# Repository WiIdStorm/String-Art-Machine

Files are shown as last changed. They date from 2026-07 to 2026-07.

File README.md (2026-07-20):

# String-Art-Machine
An automated String Art machine that performs both the automated nailing process and the string weaving process.

## Introduction

This project presents an automated String Art machine designed to handle both the automated nailing and string weaving processes. The system architecture integration and control flow are built upon the following core components:

* **Control Unit & Embedded System:** Powered by an **ESP32-WROOM-32** microcontroller managing real-time motion control, sensor data processing, and execution commands.
* **Software & Image Processing:** A **Python**-based framework is utilized to convert digital source images into optimized string-path coordinates and numerical control data.
* **Position Tracking & Feedback System:** To ensure high-precision positioning and prevent accumulative mechanical errors during operation, the system employs a robust feedback mechanism:
  * A **NEMA23 Closed-Loop Stepper Motor** with an integrated encoder to prevent step loss.
  * **Optical Limit Switch Endstops** serving as red-light sensors for precise homing, position validation, and path tracking.

## Hardware Components

The primary hardware and mechatronic components utilized in this project are listed below along with their corresponding visual documentation and technical reference links:

### 1. Controllers & Microcontrollers
* **Microcontroller:** [ESP32-WROOM-32](https://documentation.espressif.com/esp32-wroom-32_datasheet_en.pdf)(Handles real-time motion control and sensor data processing)

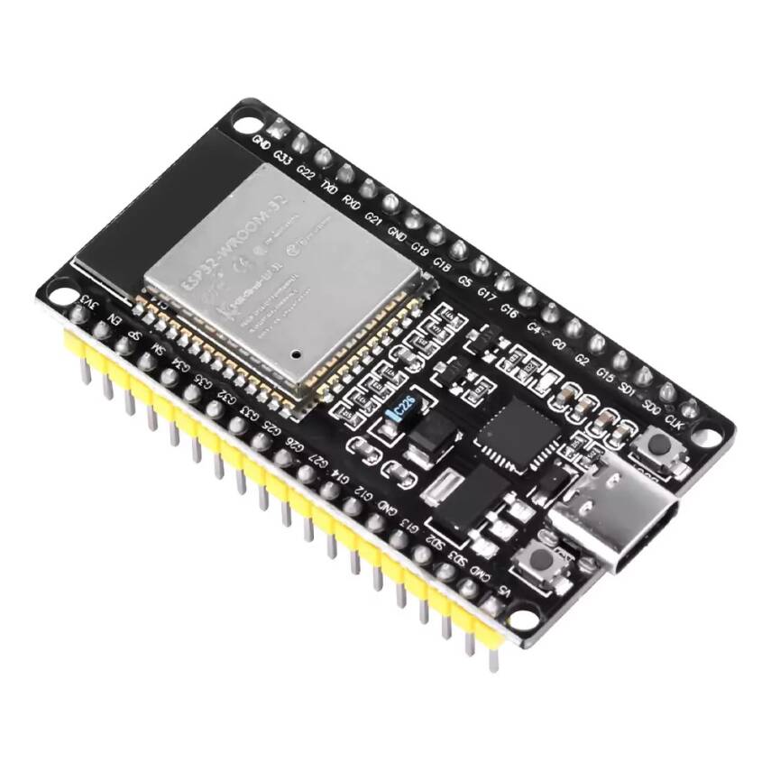
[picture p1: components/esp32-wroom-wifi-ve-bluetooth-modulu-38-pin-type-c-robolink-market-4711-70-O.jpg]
ESP32 WROOM 32


* **Signal Converters:** [MAX485 / RS485-TTL Module](https://login.pcbpower.com/Documents/0252d3ac-d61f-43a7-9b96-010299e5181c/PM14058.pdf) (Converts RS485 differential signals from encoders into TTL logic for the ESP32)

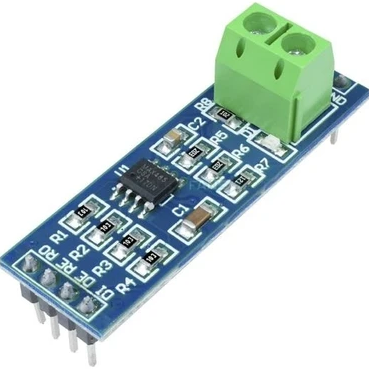
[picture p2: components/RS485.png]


### 2. Actuators, Drivers & Encoders
* **Motor:** [NEMA23 Closed Loop Stepper Motor (CS-M22323)](https://www.damencnc.com/userdata/file/6023-3_Closed_Loop_Stepper_Motor_NEMA23-2.3Nm_CS-M22323_2D_Dimensions.pdf) (2.3 Nm) with integrated encoder to prevent step loss.

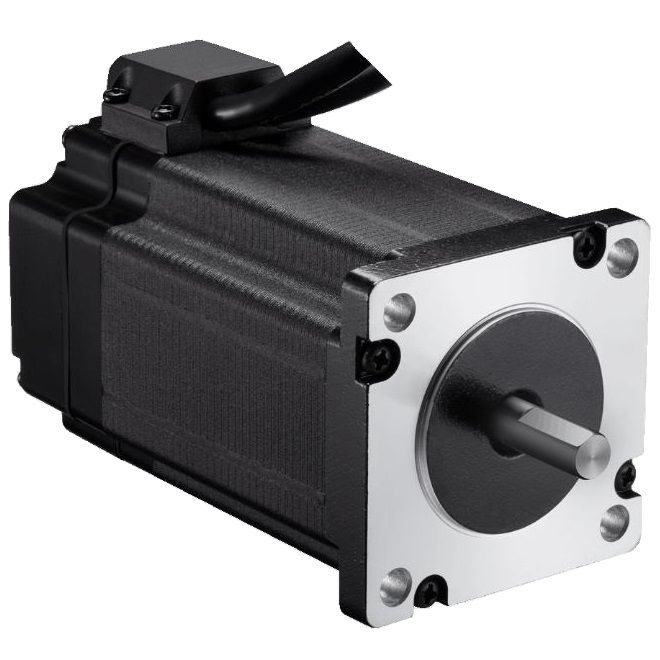
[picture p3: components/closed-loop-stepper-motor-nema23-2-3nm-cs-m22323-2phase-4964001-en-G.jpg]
NEMA23 Closed Loop Stepper Motor


* **Driver:** [CS-D508 Encoder-Integrated Stepper Motor Driver](http://leadshineusa.com/UploadFile/Down/CS-D508_m3.1.pdf) (24-48V).

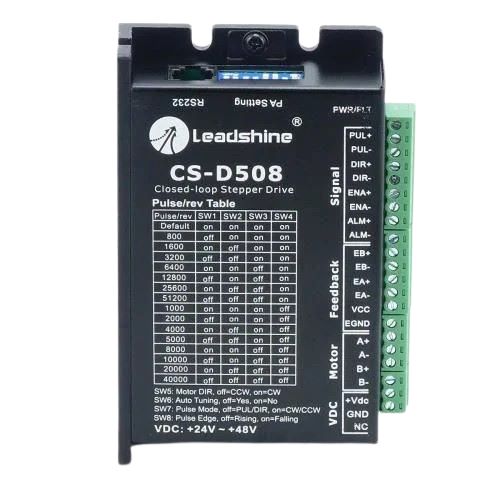
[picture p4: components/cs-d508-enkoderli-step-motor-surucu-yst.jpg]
CS-D508 Motor Driver


* **Drill Motor:** [RS-775 DC Motor](https://www.handsontec.com/dataspecs/motor_fan/775-Motor.pdf) (High-torque DC motor driving the drilling mechanism).

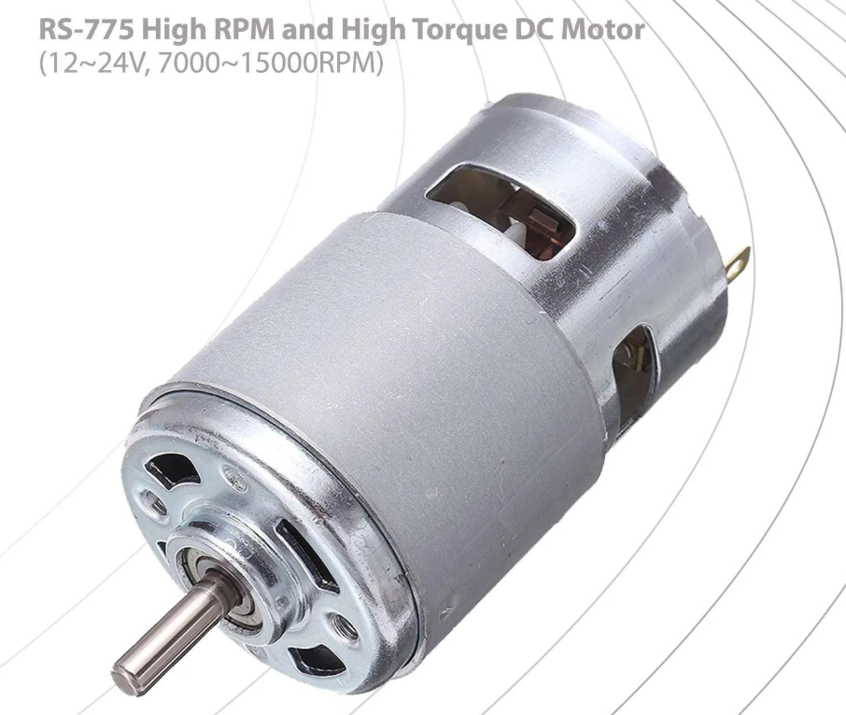
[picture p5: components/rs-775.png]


* **Servos:** [MG995 TowerPro Metal Gear Servo](https://www.electronicoscaldas.com/datasheet/MG995_Tower-Pro.pdf) (High-torque servos used for the drill depth actuation and slider mechanisms).

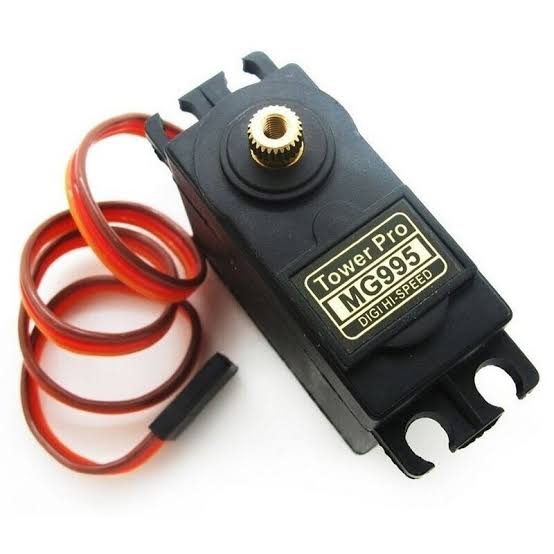
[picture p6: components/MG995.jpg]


### 3. Power Supplies (SMPS)
The system utilizes dedicated Switch Mode Power Supplies to separate power stages for stability:
* **48V Supply:** [MT-500-48 SMPS](https://mervesanteknoloji.com/statics/file/MT-500-xx-_2.pdf) (48V, 10A) - Powering the main motor drivers.

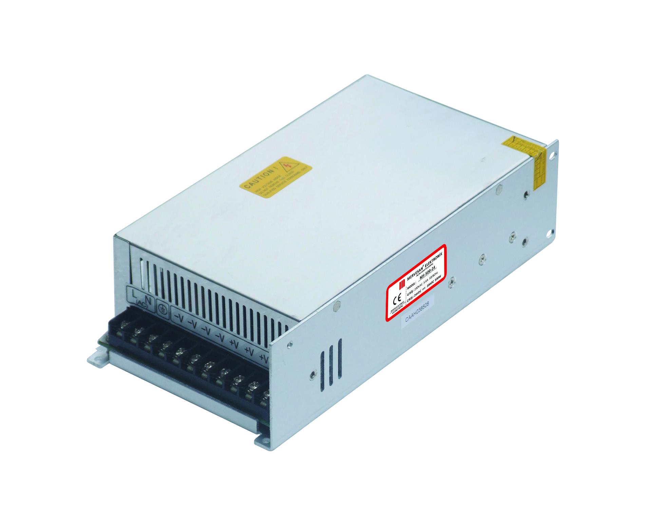
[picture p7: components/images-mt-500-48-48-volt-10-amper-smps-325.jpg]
48V 10A SMPS


* **36V Supply:** [MT-350-36 SMPS](https://mervesanteknoloji.com/statics/file/2020-6-8_user_manual_MT-350-XX_2_1.pdf) (36V, 10A).

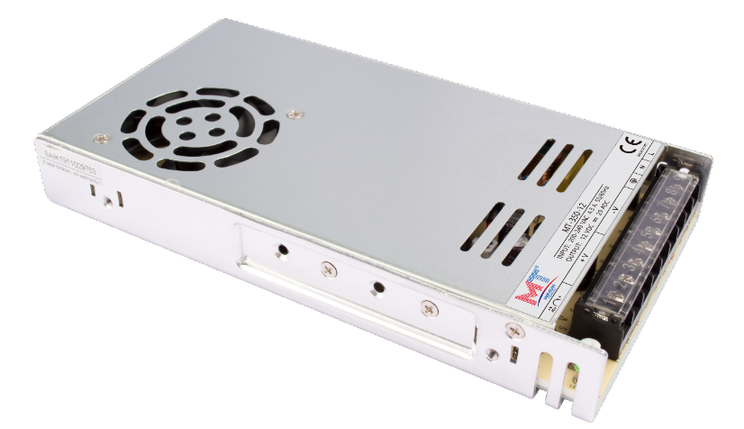
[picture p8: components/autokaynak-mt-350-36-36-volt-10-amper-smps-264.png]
36V 10A SMPS


* **24V Supply:** [Mervesan MT-250-24 SMPS](https://mervesanteknoloji.com/statics/file/MTLRS-250-24_Manua_ver-1.0.pdf) (24VDC, 10A).

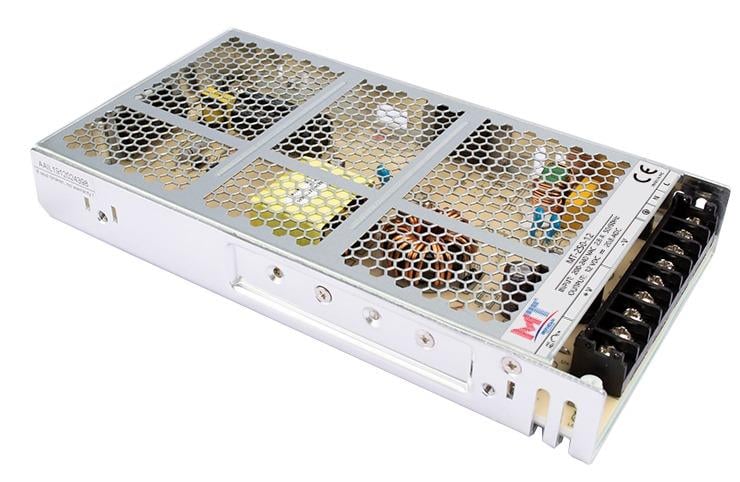
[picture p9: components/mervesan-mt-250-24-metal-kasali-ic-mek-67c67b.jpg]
24V 10A SMPS


### 4. Voltage Regulation (DC-DC Step-Down)
* **High-Power Buck Converters:** 3x [XL4016 DC-DC Step Down Regulator Modules](https://www.mikrocontroller.net/attachment/534859/XL4016_Step_Down_Buck_DC_DC_Converter.pdf) (300W, 10A).
  * *Note on Implementation:* One of these buck converters replaces a standard XL4016 module, as the high-capacity XL4016 was readily available and deployed to maintain power consistency across the logic and sensor circuits.

| XL4016 300w | XL4016 200w |
| :---: | :---: |
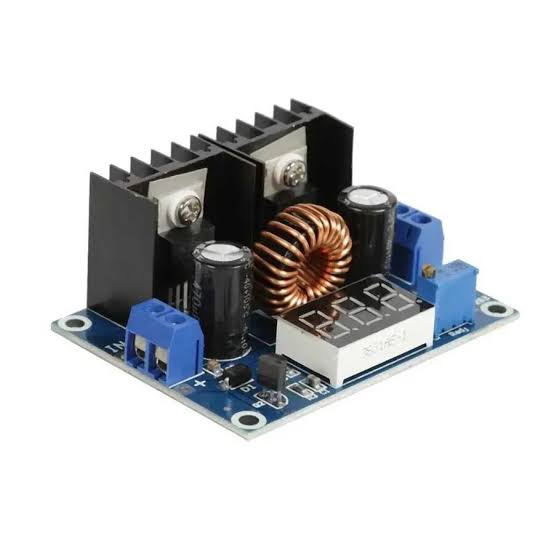
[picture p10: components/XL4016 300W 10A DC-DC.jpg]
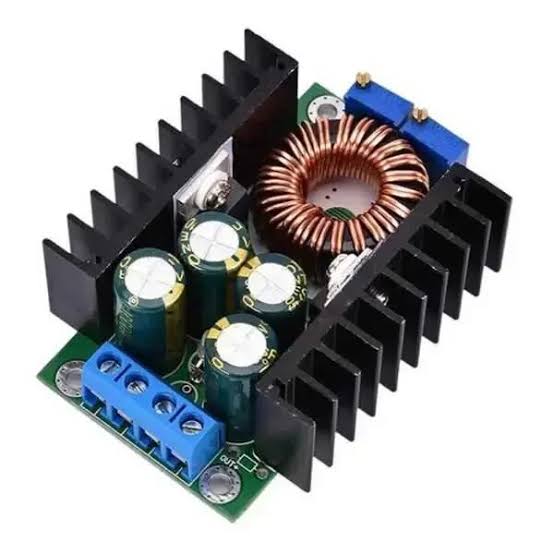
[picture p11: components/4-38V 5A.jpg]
|  |  |

### 5. Sensors & Position Tracking
* **Optical Sensors:** [Optical Limit Switch Endstops](https://www.handsontec.com/dataspecs/sensor/Optical%20end%20stop.pdf) (Dimensions: 33 x 12 x 10 mm) used for precise homing, position validation, and path tracking.

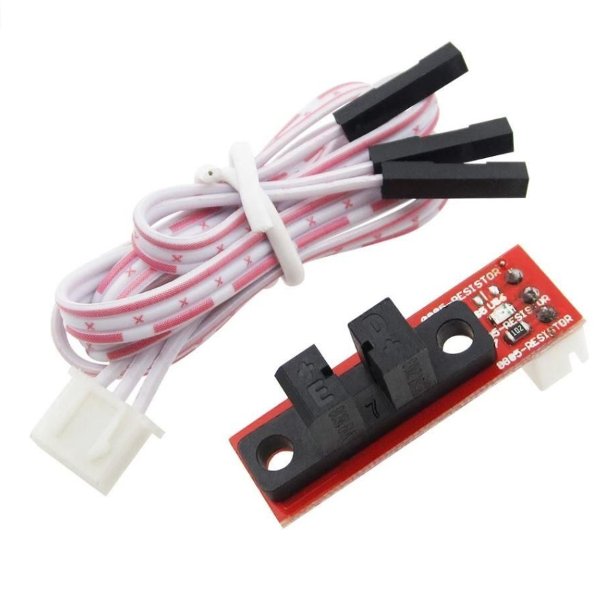
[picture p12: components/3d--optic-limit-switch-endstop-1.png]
Optical Limit Switch Endstop


## Mechanical Design & Assembly

The mechanical structure of the String Art machine is detailed in this section. The design progresses from the top-level system assembly down to the individual custom-designed components.

### 1. System Overview (Top View)
The main layout of the system, illustrating the positioning and integration of the mechanical and electronic sub-assemblies, is provided below.

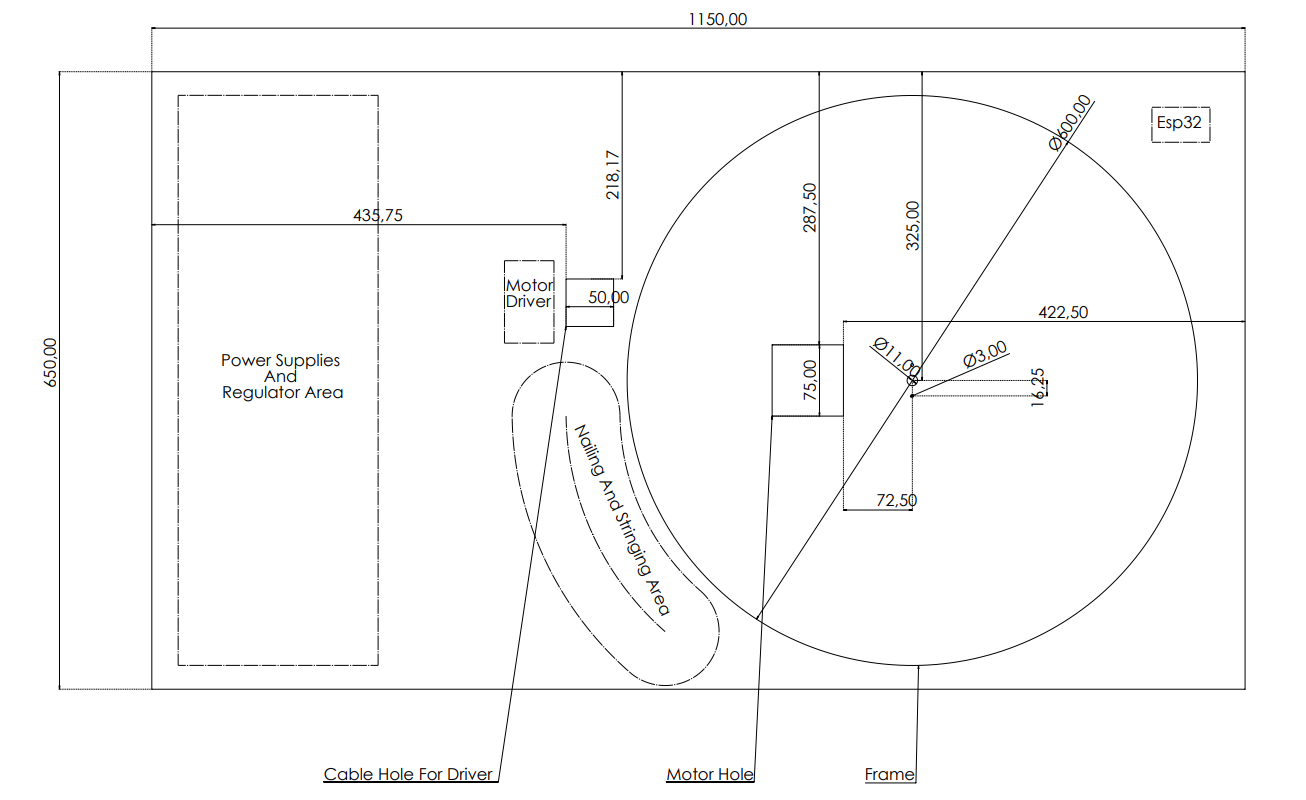
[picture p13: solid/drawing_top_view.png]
Top View Technical Drawing


* **Top View Drawing:** [`drawing_top_view.pdf`](./solid/drawing_top_view.pdf)
### 2. Custom Components
The following custom parts were designed for the physical construction of the machine. Universal `.step` files are provided for replication, alongside visual references for each component.

* **Drill Main Unit:** Core housing for the drilling mechanism.
  
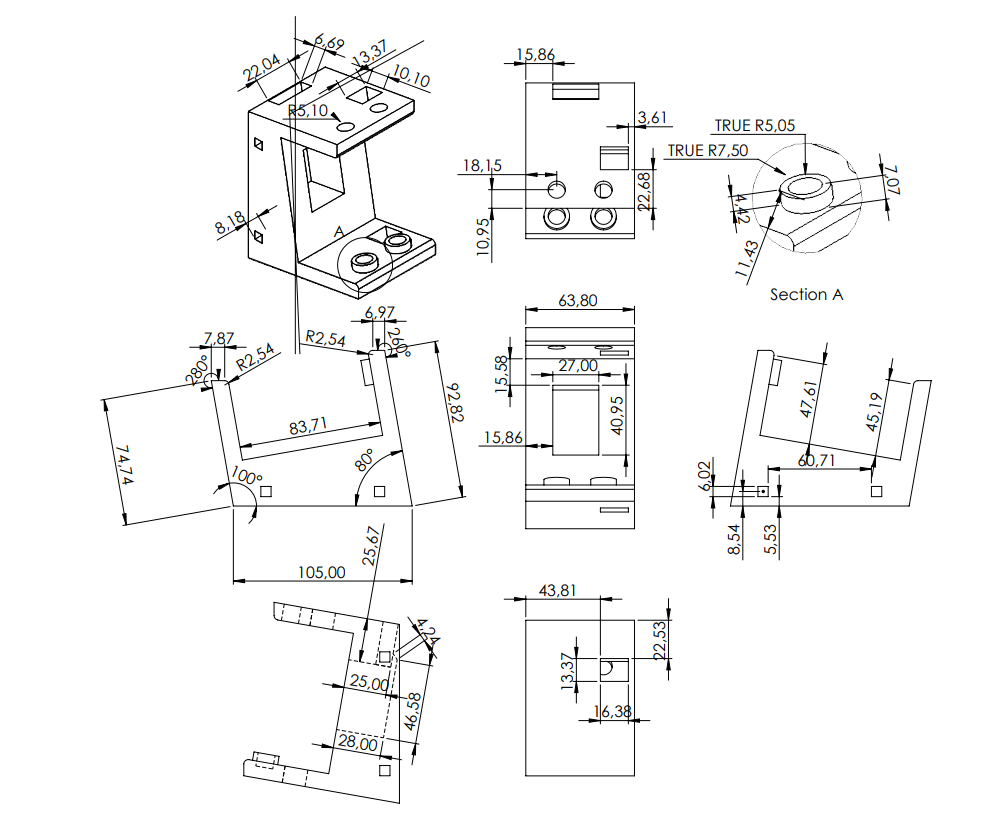
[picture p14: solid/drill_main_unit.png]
  

  * **File:** [`drill_main_unit.step`](./solid/drill_main_unit.step)
* **Drill Mounting Rod:** Structural support component for the drill unit.
  
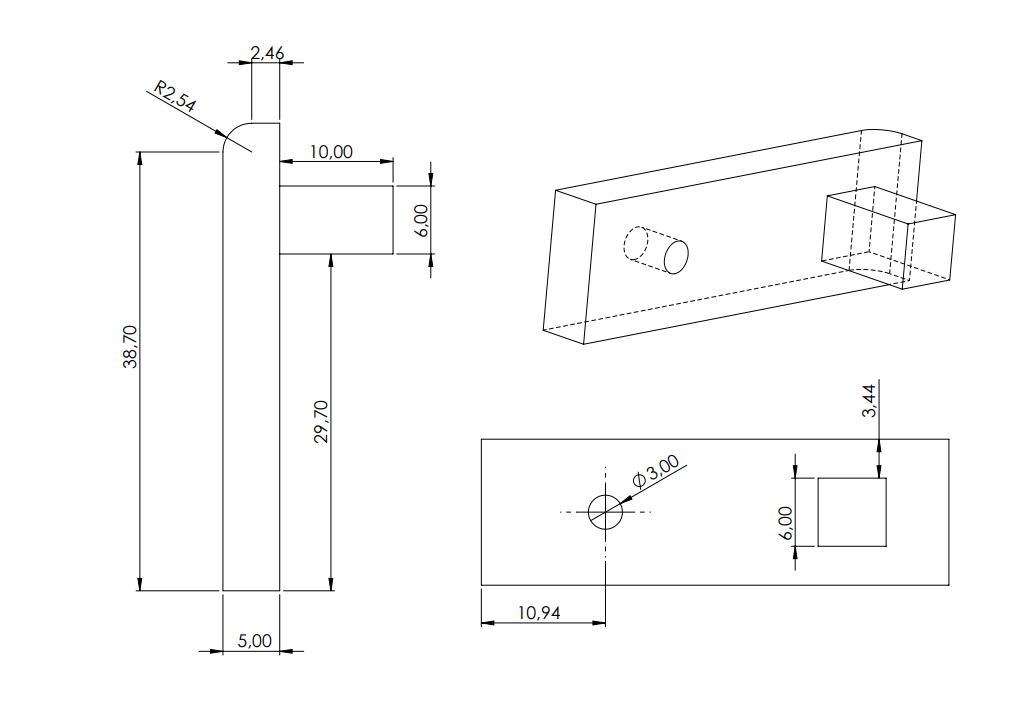
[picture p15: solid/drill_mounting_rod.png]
Drill Mounting Rod
  

  * **File:** [`drill_mounting_rod.step`](./solid/drill_mounting_rod.step)
* **Drill Servo Gear:** Transmission gear for the servo-actuated mechanism.

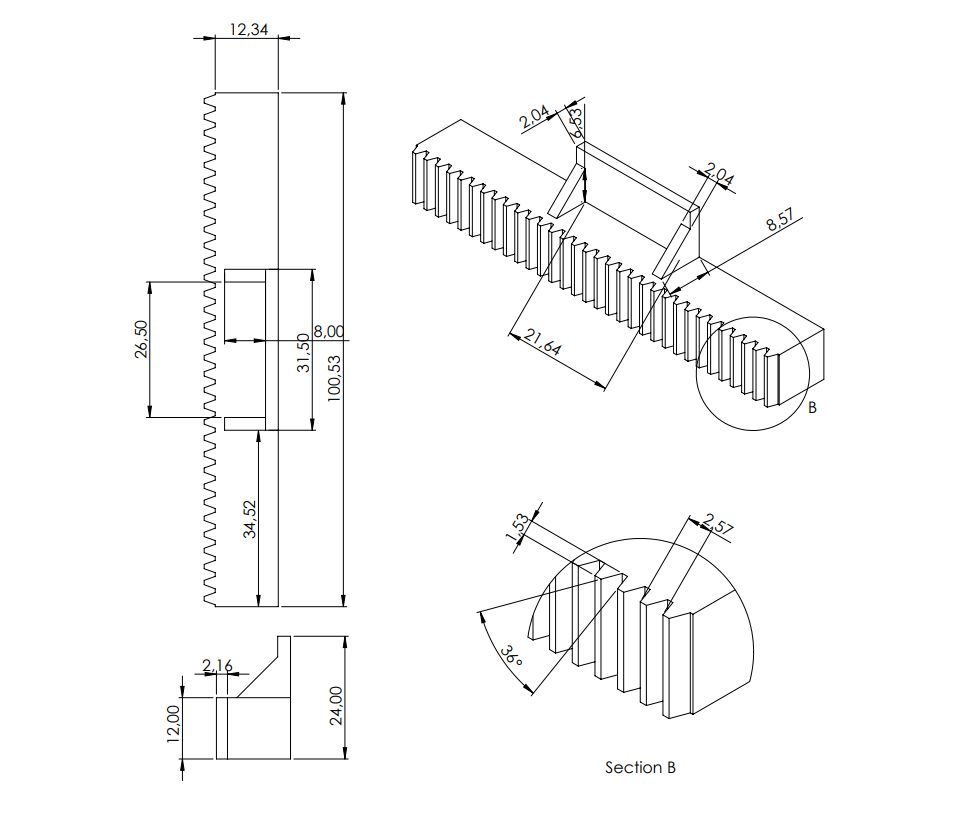
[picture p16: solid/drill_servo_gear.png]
Drill Servo Gear
  

  * **File:** [`drill_servo_gear.step`](./solid/drill_servo_gear.step)
* **Motor Mount:** Bracket designed to secure the NEMA23 closed-loop stepper motors.
  
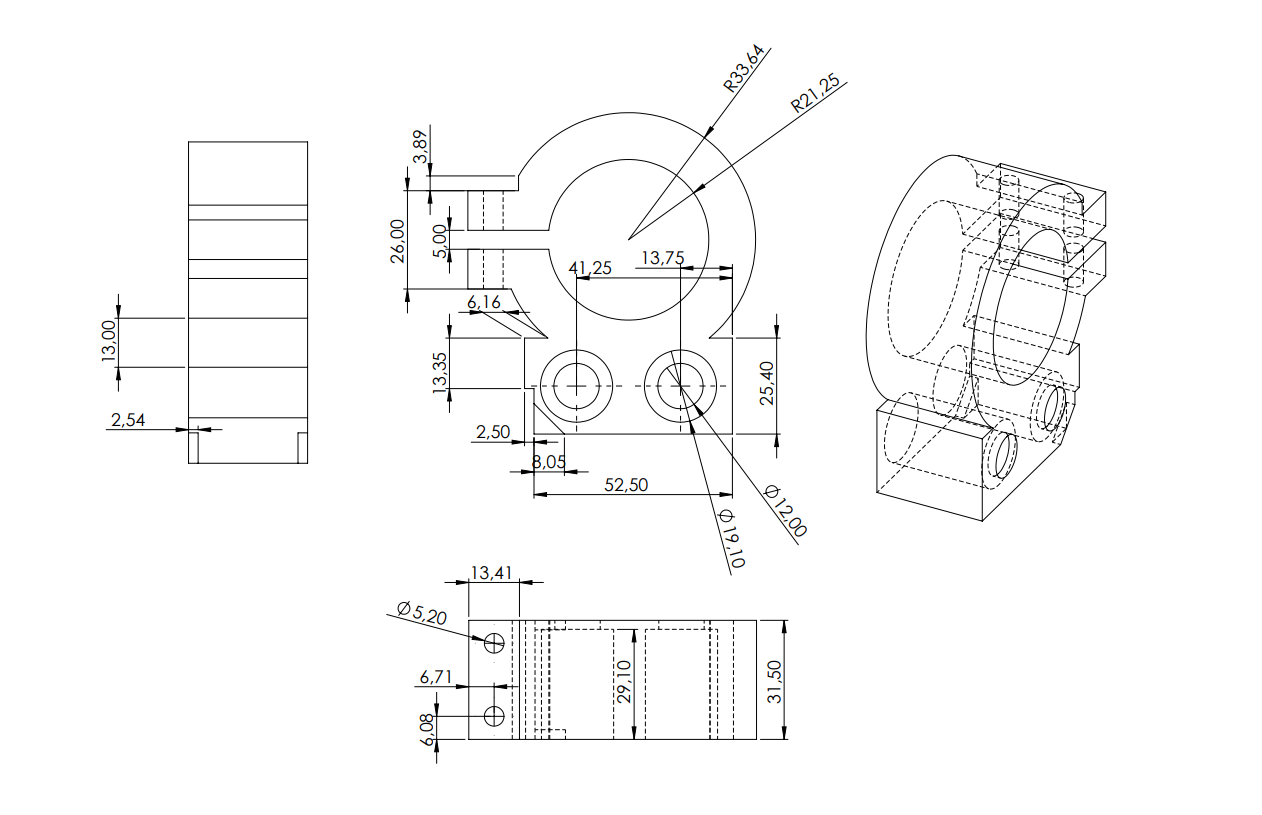
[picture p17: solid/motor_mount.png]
Motor Mount
  

  * **File:** [`motor_mount.step`](./solid/motor_mount.step)
* **Slider End:** End effector and guide component for the linear motion axis.
  
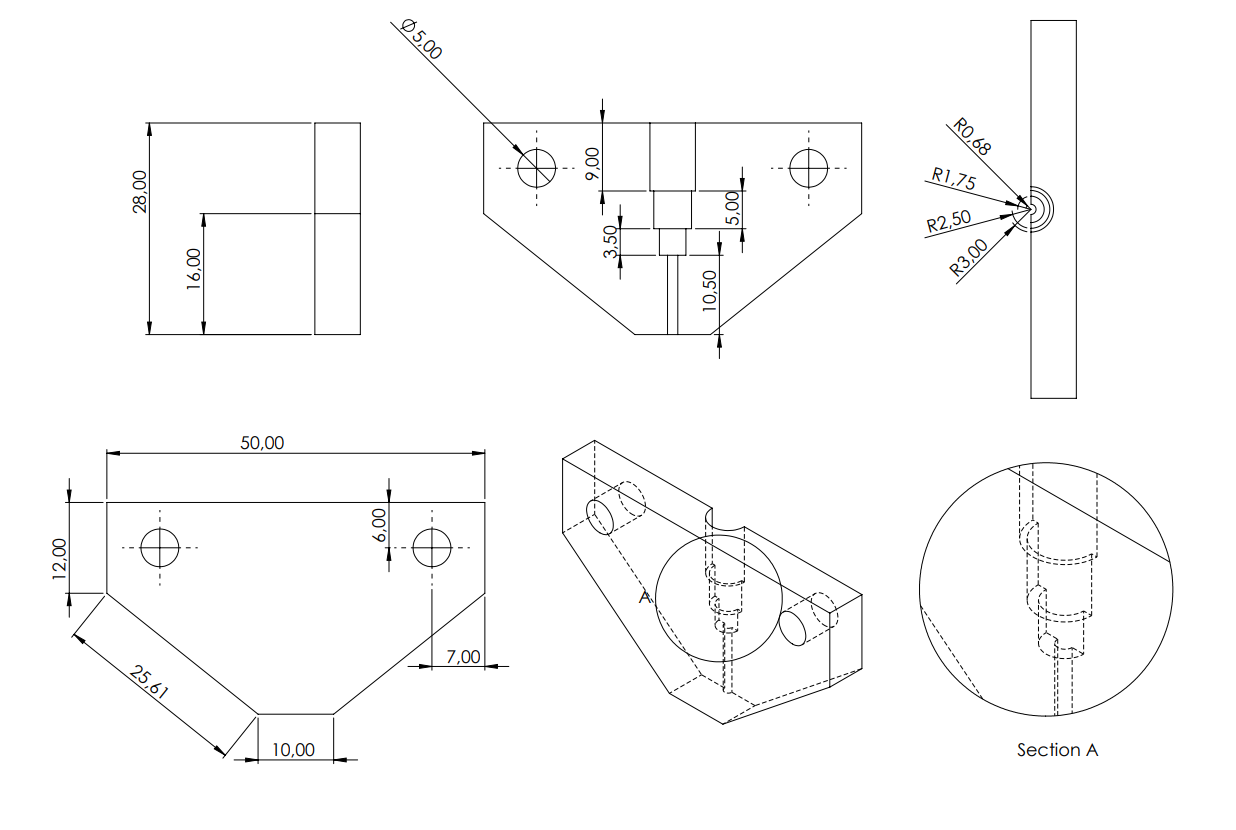
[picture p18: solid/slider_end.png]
Slider End
  

  * **File:** [`slider_end.step`](./solid/slider_end.step)
* **Chassis:** The primary structural frame supporting the entire operation.
 
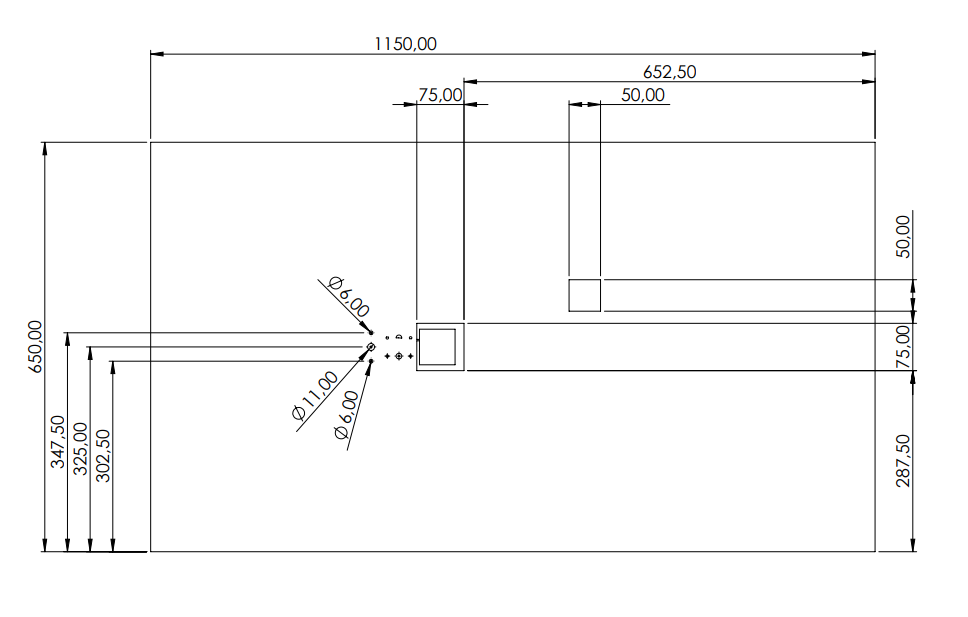
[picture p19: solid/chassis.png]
Chassis
  

  * **File:** [`chassis.step`](./solid/chassis.step)
* **Table / Bed:** The main work surface where the string art generation takes place.
  
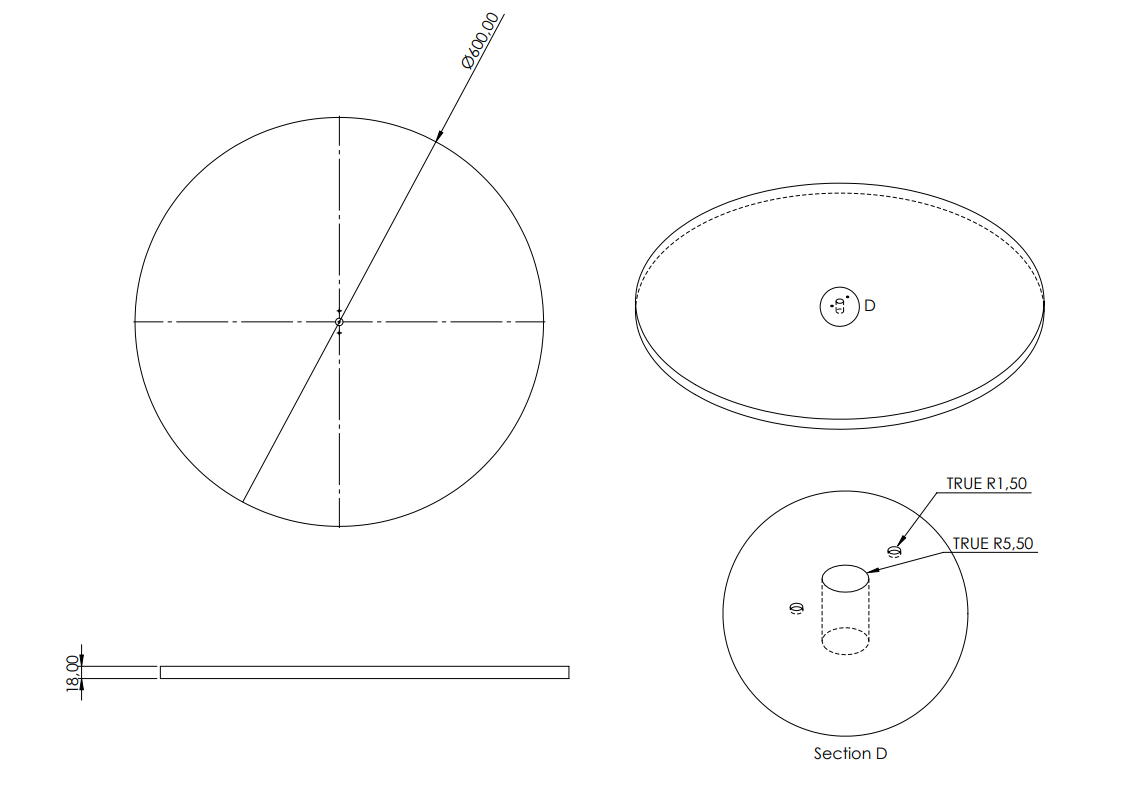
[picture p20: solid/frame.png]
Frame
  

   * **File:** [`table_bed.step`](./solid/frame.step)

## System Wiring & Connections

To ensure system stability, prevent step loss, and protect the low-voltage microcontroller components, the electrical architecture is divided into three isolated stages. 

*(Note: Ensure all sub-systems share a physical **Common GND** network to prevent signal noise).*

### 1. Power Distribution Layout
This section details the AC-to-DC power routing, voltage regulation stages, and the common ground network used to power the system.

* **AC Mains Input:** 220V AC grid ($L, N, \text{PE}$) supplies power to the primary SMPS units.
* **Main SMPS Units (Power Supply):** 
  * **MT-500-48 SMPS (48V, 10A):** Dedicated to powering the main NEMA23 closed-loop stepper motor driver (CS-D508).
  * **MT-350-36 SMPS (36V, 10A):** Supplies power for the auxiliary motor drivers.
  * **Mervesan MT-250-24 SMPS (24V, 10A):** Provides base voltage for DC motor drivers and DC-DC step-down modules.
* **DC-DC Step-Down Stages (Voltage Regulation):**
  * **XL4016 Buck Converter 1:** Steps down voltage to **5V** to supply logic power for sensors, encoders, servos, and level shifters.
  * **XL4016 Buck Converter 2:** Steps down voltage to **3.3V** to power the ESP32 microcontroller.

### 2. Logic Level Shifting & MCU Interface
This section details the control signal pathways and pin mappings between the low-voltage ESP32 and the 5V peripheral interfaces.

The ESP32 operates at a **3.3V logic level**. Level shifters are dedicated specifically to stepping down **5V signal outputs** (such as encoder receiver outputs, sensor signals, and driver feedback) down to **3.3V** to protect the ESP32 GPIO pins, while control output signals are driven directly from the microcontroller.

| Component | Signal Type | ESP32 Pin (3.3V) | Level Shifter Direction | Peripheral Pin (5V) |
| :--- | :--- | :---: | :---: | :--- |
| **Stepper Driver (CS-D508)** | Pulse | `P18` | Direct (3.3V) | `PUL+` (Blue) |
| | Direction | `P19` | Direct (3.3V) | `DIR+` (Brown) |
| | Enable | `P17` | Direct (3.3V) | `ENA+` (Green) |
| | Alarm | `P16` | 5V $\rightarrow$ 3.3V | `ALM+` (Orange) |
| **DC Motor Driver (BTS7960)**| Forward PWM | `P26` | Direct (3.3V) | `RPWM` |
| | Reverse PWM | `P27` | Direct (3.3V) | `LPWM` |
| | Right Enable | `P25` | Direct (3.3V) | `R_EN` |
| | Left Enable | `P25` | Direct (3.3V) | `L_EN` |
| **Servos (MG995)** | Drill PWM | `P21` | Direct (3.3V) | Signal (Drill Servo) |
| | Slider PWM | `P14` | Direct (3.3V) | Signal (Slider Servo) |
| **Encoders (RS485-TTL)** | Encoder 1 (RO) | `P22` | 5V $\rightarrow$ 3.3V | `RO` (Green/Red) |
| | Encoder 2 (RO) | `P23` | 5V $\rightarrow$ 3.3V | `RO` (Yellow/Blue) |
| **Sensors** | Optical Sensor | `P32` | 5V $\rightarrow$ 3.3V | Signal Output |

### 3. Actuators & Closed-Loop Feedback Connections
This section outlines the high-current drive outputs, motor phase connections, and hardware-level feedback routing.

* **Main Motion Control:**
  * The **CS-D508 Stepper Driver** receives power from the 48V SMPS and outputs high-current drive signals to the **NEMA23 Closed-Loop Stepper Motor (CS-M22323)** phases.
  * **Feedback Loop:** The integrated encoder on the rear of the NEMA23 motor routes directly back to the dedicated feedback port on the CS-D508 driver. This ensures hardware-level correction to prevent step loss without adding processing overhead to the ESP32.
* **Auxiliary Actuation (Nailing & Stringing Mechanisms):**
  * The **BTS7960 DC Motor Driver** controls the **RS-775 DC Motor** for high-torque operations (such as the drilling/nailing spindle).
  * The **MG995 Servos** draw power from the 5V regulated line and receive direct PWM signals from the ESP32 to actuate the slider and depth mechanisms.

## System Integration & Real-World Assembly

This section documents the physical construction of the String Art machine, showcasing the integration of mechanical parts, electronics, and the execution of the main automated processes.

### 1. Electronics & Control Assembly
* **ESP32 & Breakout Integration:** Real-world wiring and terminal block assignments on the main ESP32 development board.

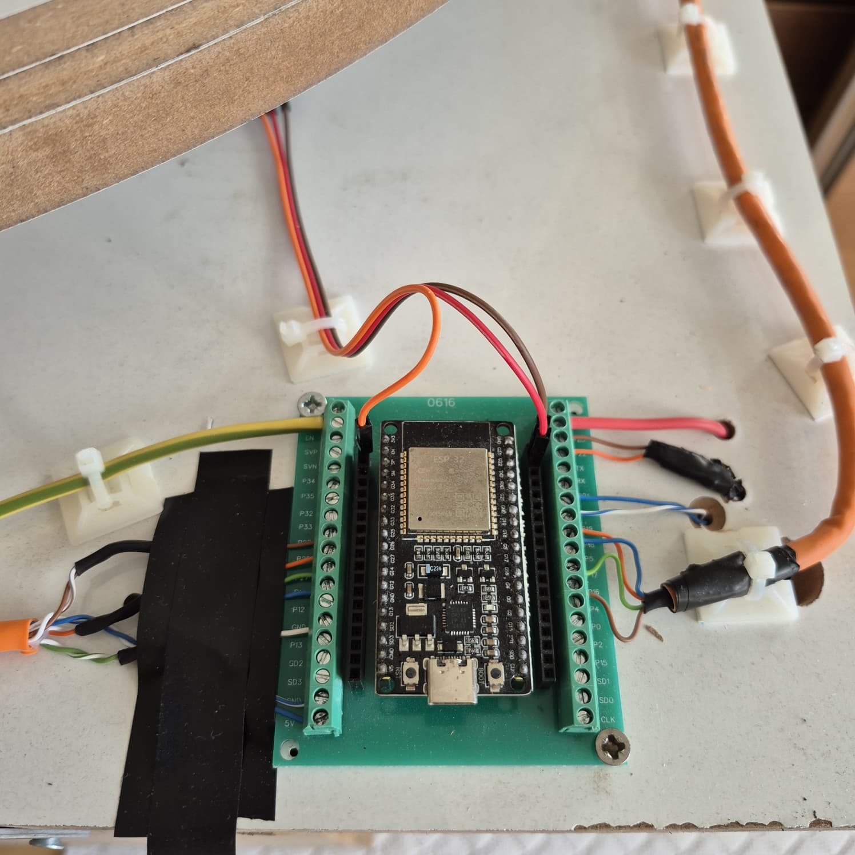
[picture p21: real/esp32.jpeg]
ESP32 Controller Unit
  

* **Stepper Driver & Signal Cabling:** Industrial CS-D508 stepper motor driver wired to the motor phase lines and control bus.

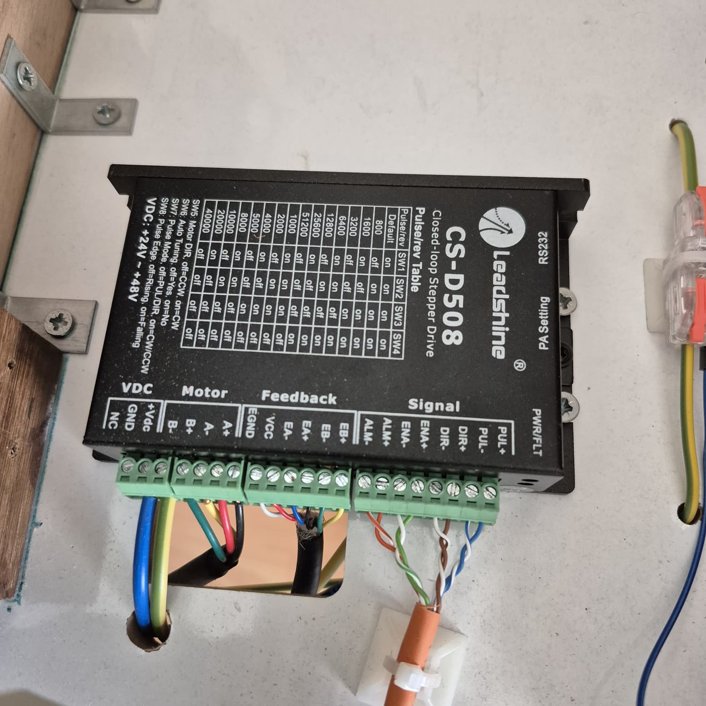
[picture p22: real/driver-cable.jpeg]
CS-D508 Stepper Driver Wiring
  

* **Logic Level Shifting & RS485 Interface:** Breadboard-based signal conditioning circuits for level shifting and differential encoder communication.

| Encoder Signal Converter | Signal Shifter (Far Side) |
| :---: | :---: |
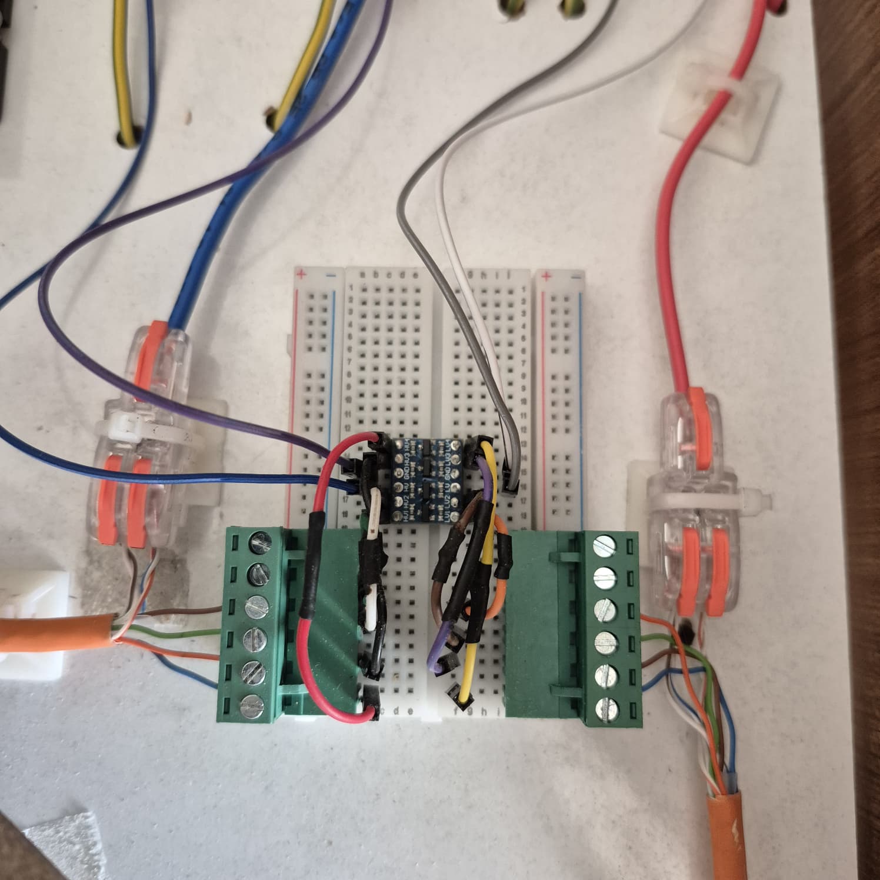
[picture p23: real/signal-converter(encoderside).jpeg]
Encoder Signal Converter
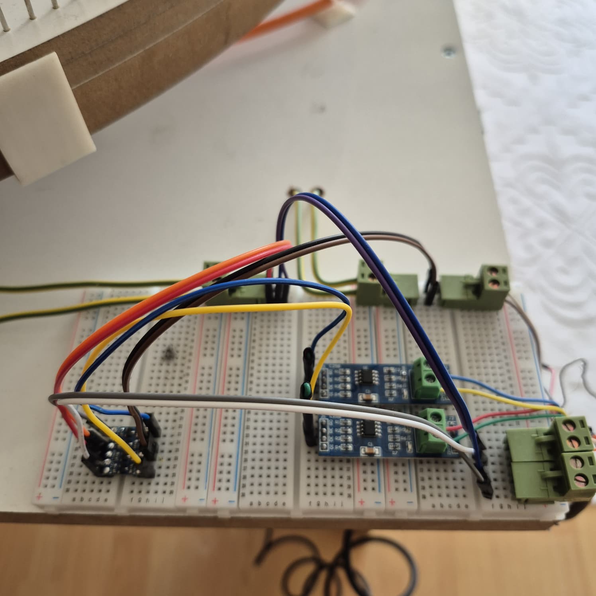
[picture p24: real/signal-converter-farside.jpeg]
Signal Converter Overview
|  |  |

---

### 2. Mechanical Integration & Feedback System
* **Rotary Encoder Assembly:** Direct shaft-coupled rotary encoder for mechanical feedback and position tracking.

| Bed Encoder Mount | Dual Motor & Encoder Integration |
| :---: | :---: |
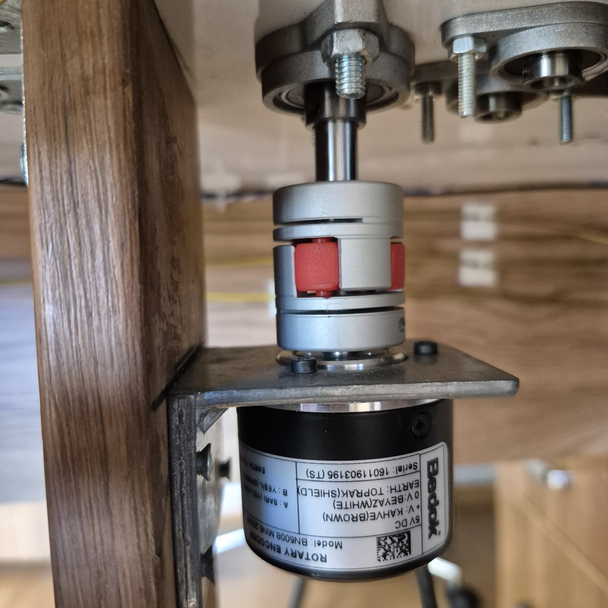
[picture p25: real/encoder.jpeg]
Rotary Encoder Assembly
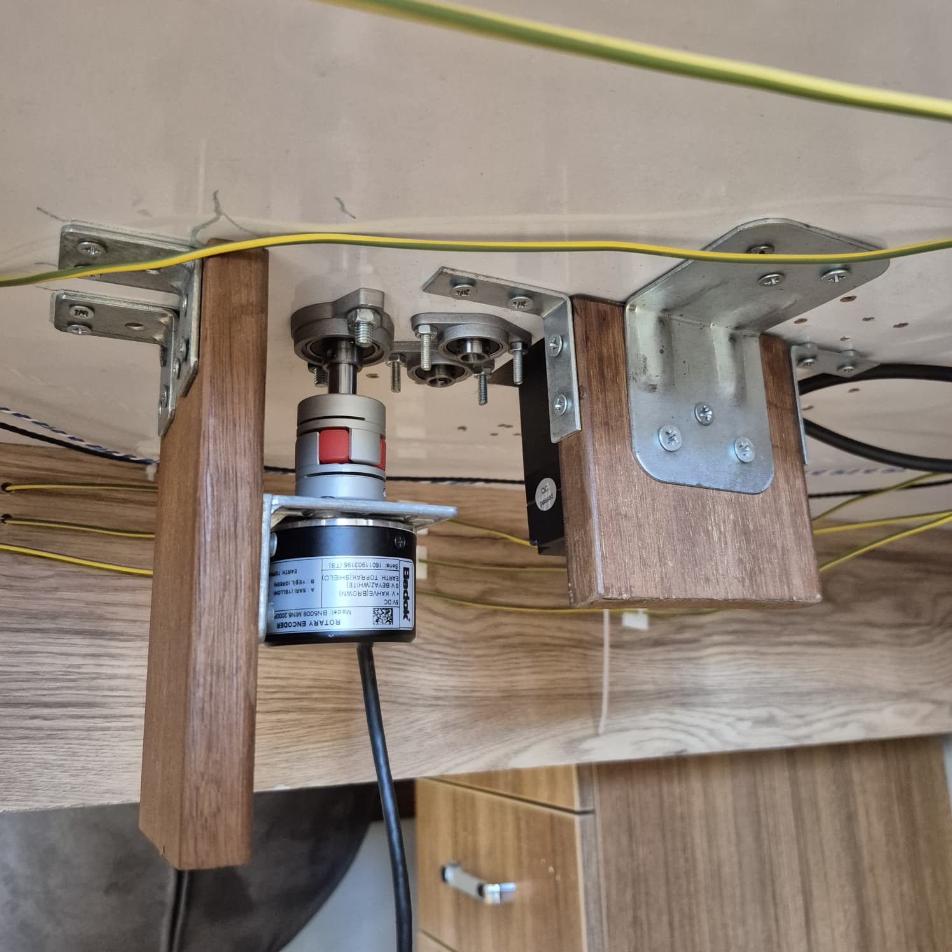
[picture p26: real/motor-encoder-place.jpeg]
Motor and Encoder Setup
|  |  |

* **Optical Homing Sensor:** Precision limit switch mounted near the rotating bed for absolute zero position validation.

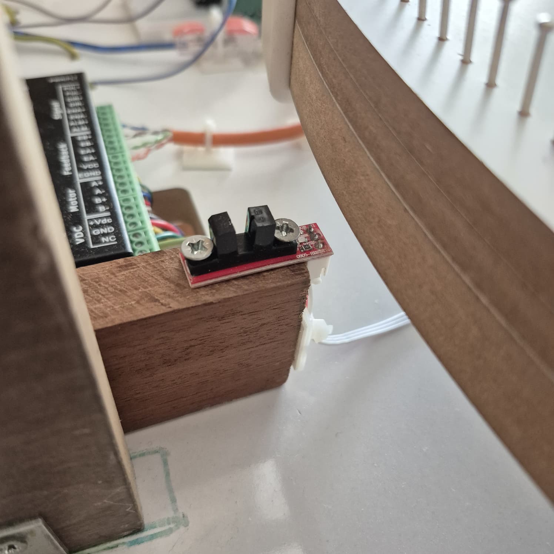
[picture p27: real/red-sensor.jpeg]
Optical Limit Switch
  

* **Power Supply & Chassis Mobility:** Power stage distribution layout and structural support caster installation.

| Power & Main Motor Setup | Chassis Caster Support |
| :---: | :---: |
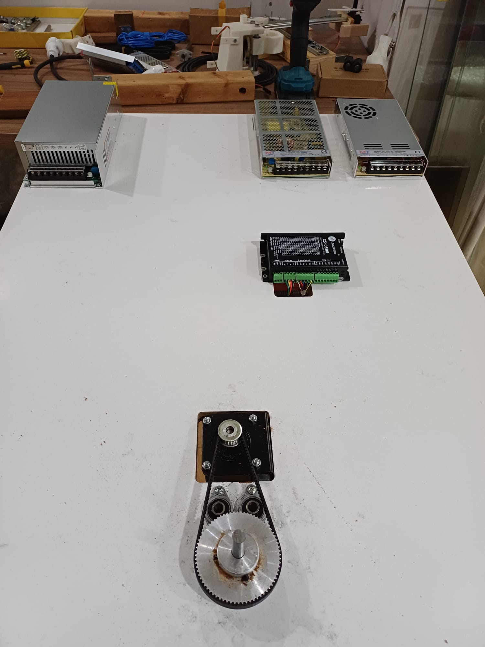
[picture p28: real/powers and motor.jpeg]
Power Supply Layout
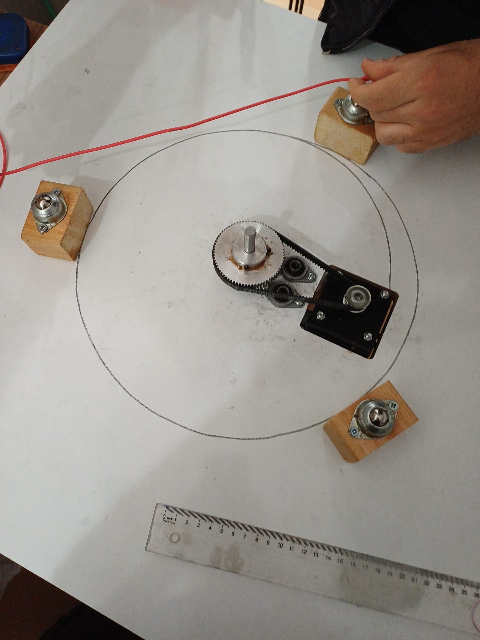
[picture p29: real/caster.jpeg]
Caster Wheel Support
|  |  |

---

### 3. Operational Stages
* **Automated Nailing Process:** The end-effector mechanism drilling guidelines and precisely inserting pins/nails into the circular bed.

| Nailing Assembly 1 | Nailing Assembly 2 | Nailing Circuit |
| :---: | :---: | :---: |
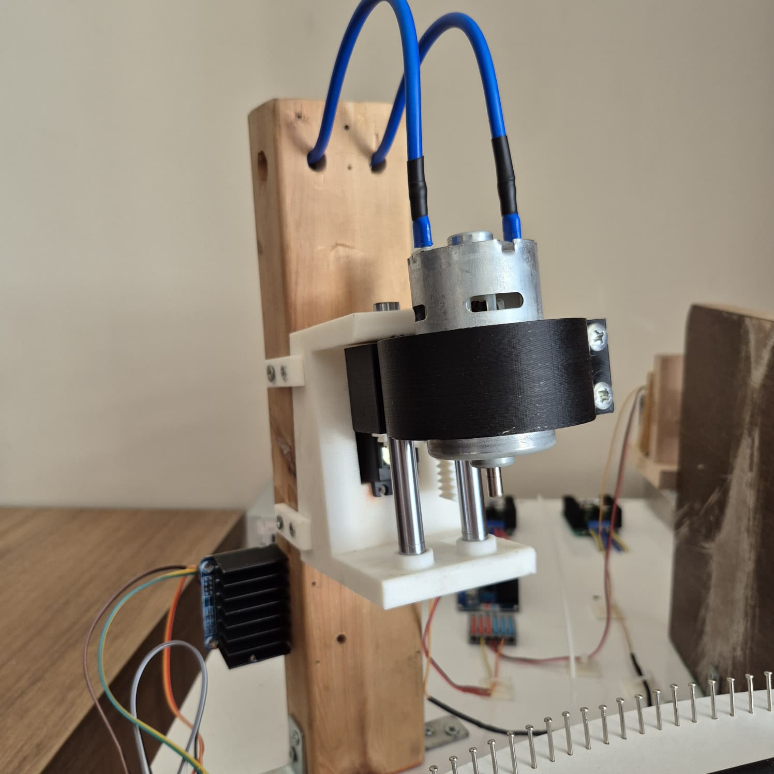
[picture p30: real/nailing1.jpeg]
Automated Nailing Process 1
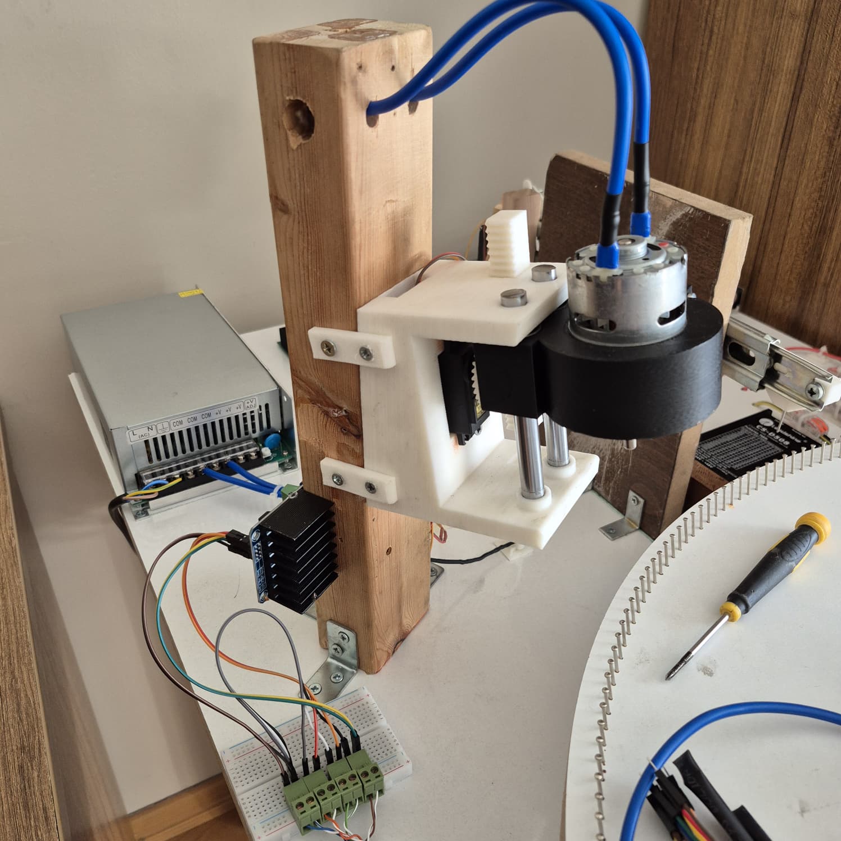
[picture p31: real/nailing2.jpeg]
Automated Nailing Process 2
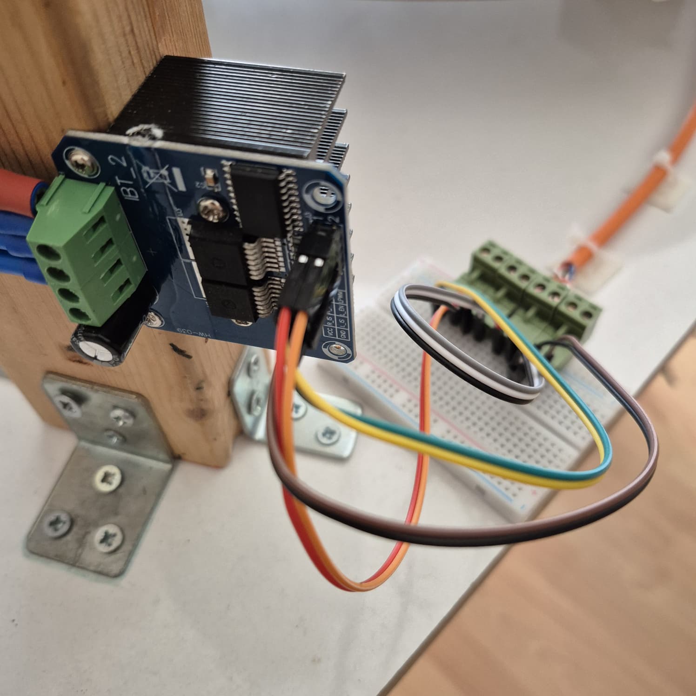
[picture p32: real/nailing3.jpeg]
Automated Nailing Process 3
|  |  |  |

* **String Weaving Process:** The automated routing of the string across the predefined coordinate paths.

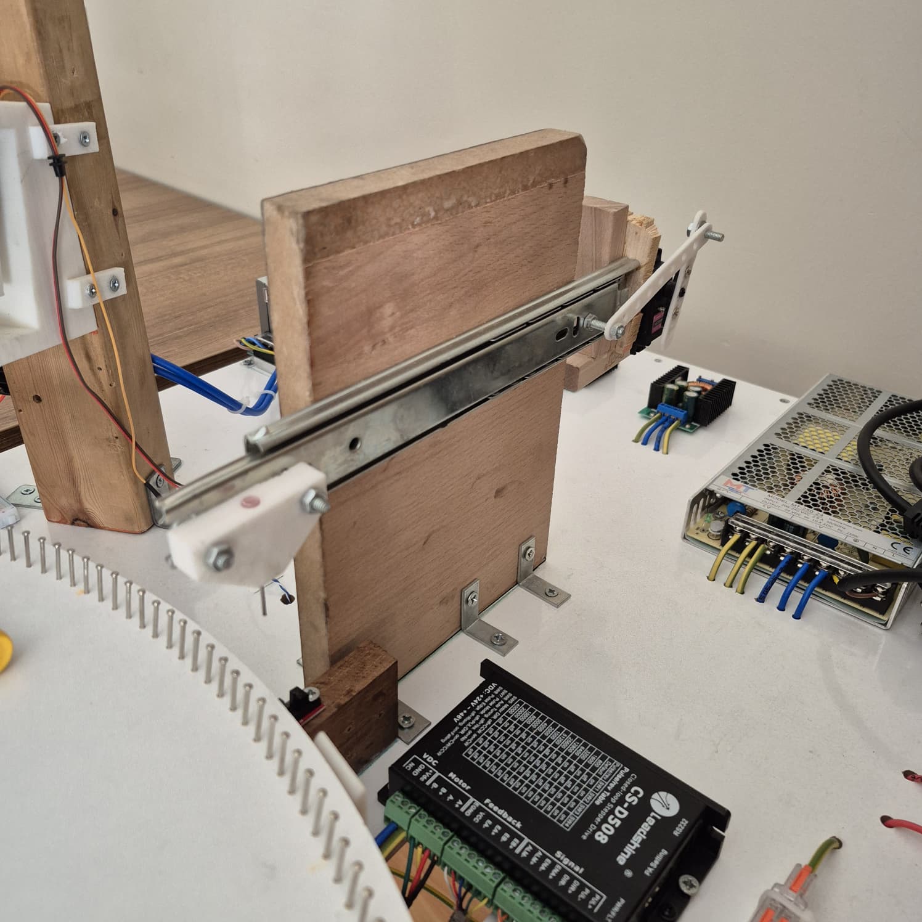
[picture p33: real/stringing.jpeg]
String Weaving Process
  

## Software Architecture & Algorithm Breakdown

This section documents the software framework and the core image-to-string processing pipeline. The complete source code files are hosted directly within the repository files.

### 1. Image Processing & String Generation Pipeline
The **Python**-based framework processes digital source images, applies localized optimization algorithms, and generates numerical control paths for the ESP32 microcontroller.

**Key Software Modules & Operations to Document:**
* **Image Pre-processing Module:** Grayscale conversion, contrast adjustment, and cropping filters.
* **Algorithm Core:** Calculations mapping string density, line intersections, and nail-to-nail path sequences.
* **Data Exporter:** Generation of numerical control data arrays and transmission protocols sent to the ESP32.

### 2. Algorithmic Transformation (Sample Input vs. Output)
Below is a visual representation of how the Python pipeline transforms a standard raster image into a vector-mapped string-art pattern:

| Source Input Image (Girdi) | Algorithmic String Output (Çıktı) |
| :---: | :---: |
| Original Input Image | Generated String Art Result |

---

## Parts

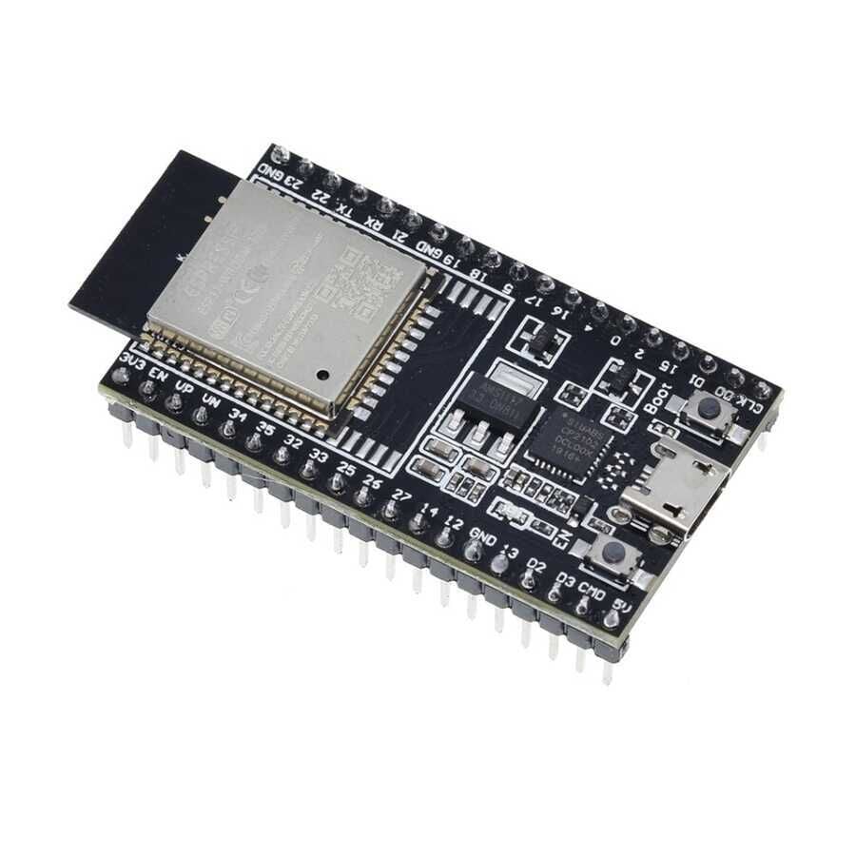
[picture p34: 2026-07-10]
components/esp32-wroom-32d-wifi-ve-bluetooth-gelistirme-karti-1.jpg

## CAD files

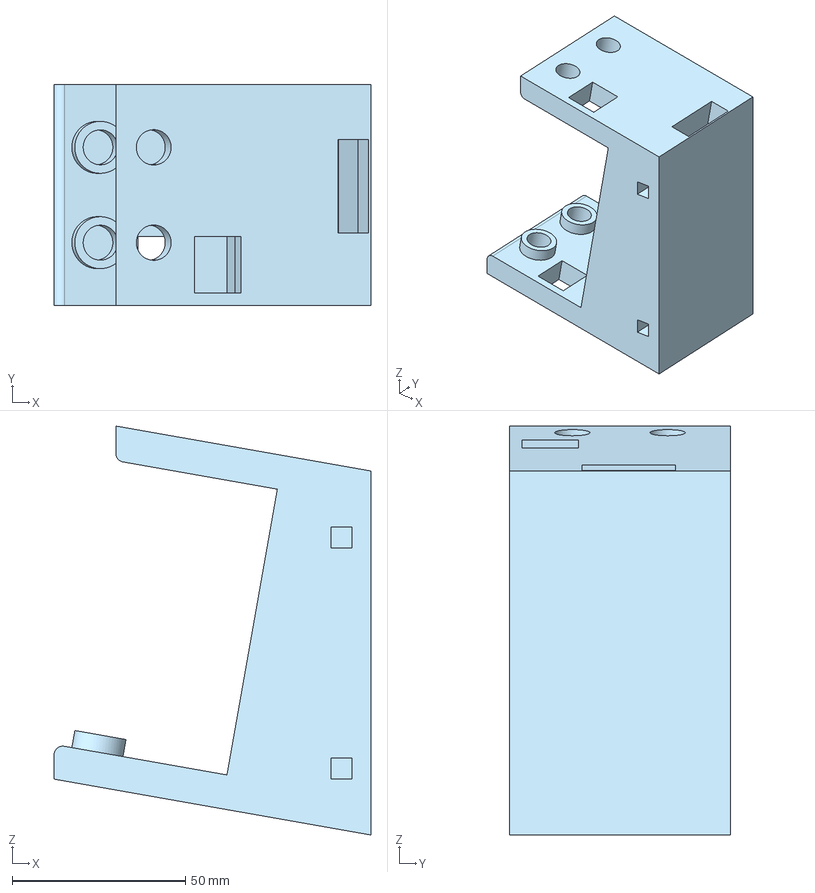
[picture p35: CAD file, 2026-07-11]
solid/drill_main_unit.step
91.4 x 63.8 x 118.0 mm

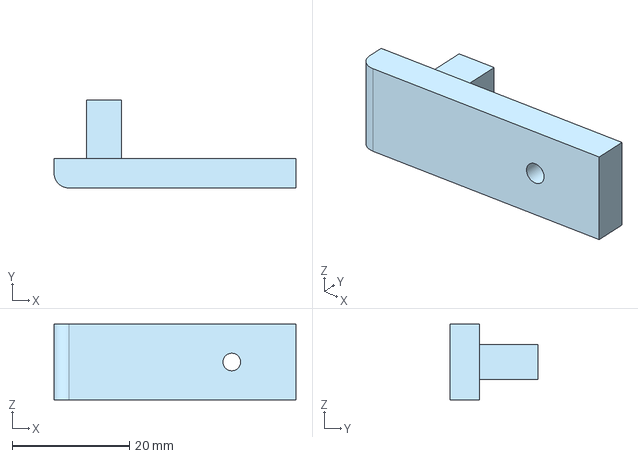
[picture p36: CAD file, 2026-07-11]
solid/drill_mounting_rod.step
41.2 x 15.0 x 12.9 mm

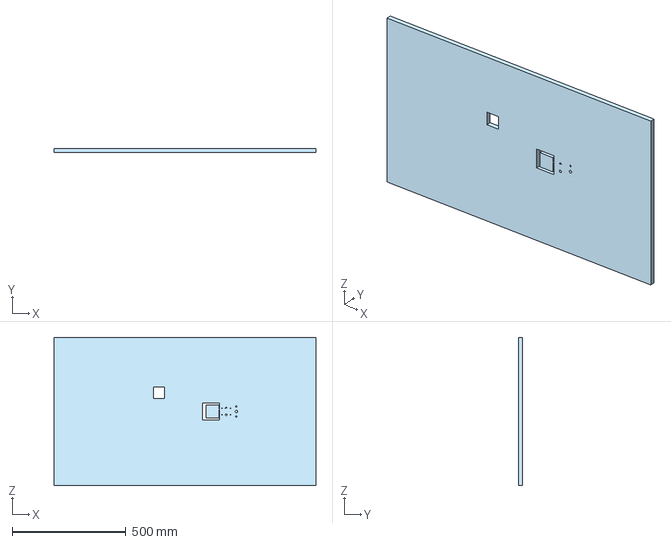
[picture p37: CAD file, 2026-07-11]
solid/chassis.step
1150.0 x 18.0 x 650.0 mm

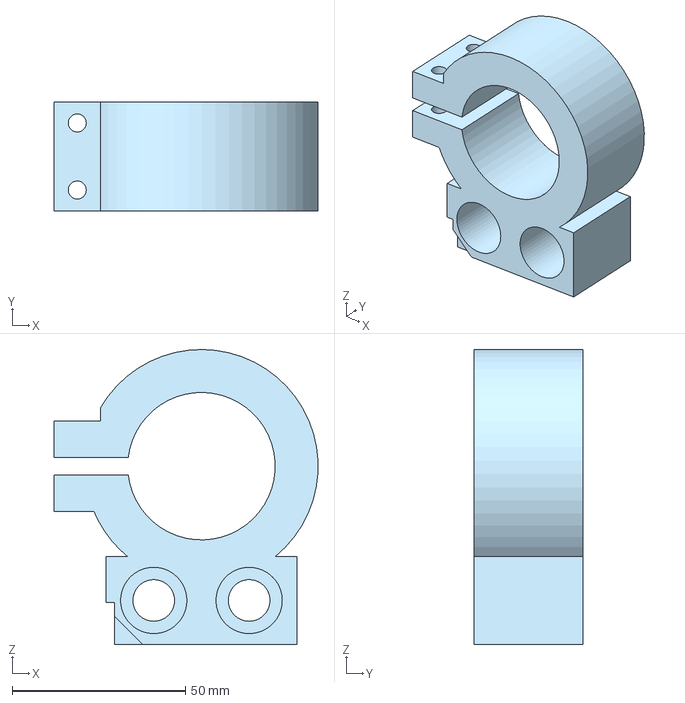
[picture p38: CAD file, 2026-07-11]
solid/motor_mount.step
76.1 x 31.5 x 85.0 mm

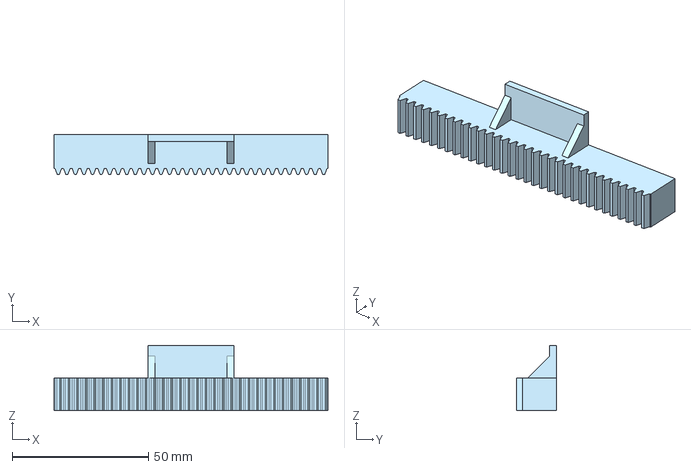
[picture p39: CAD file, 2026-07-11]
solid/drill_servo_gear.step
100.5 x 14.5 x 24.0 mm

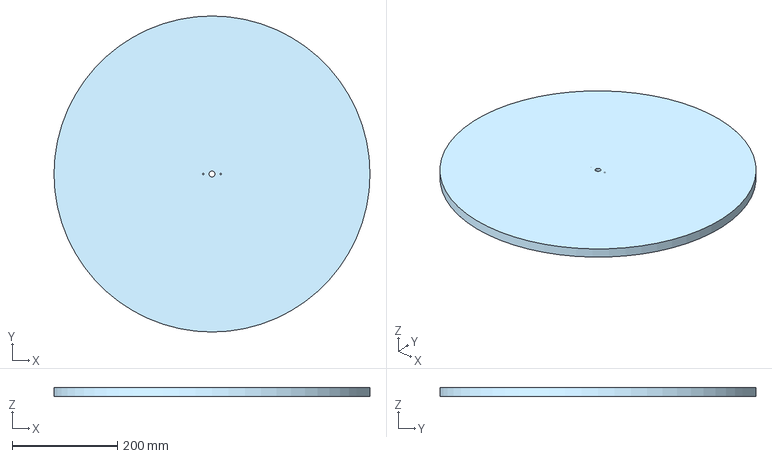
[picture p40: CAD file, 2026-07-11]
solid/frame.step
600.0 x 600.0 x 18.0 mm

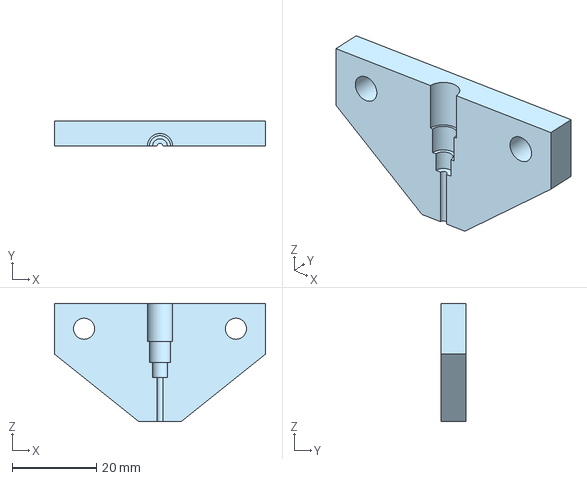
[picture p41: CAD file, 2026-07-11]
solid/slider_end.step
50.0 x 6.00 x 28.0 mm

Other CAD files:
solid/drawing_top_view.SLDDRW

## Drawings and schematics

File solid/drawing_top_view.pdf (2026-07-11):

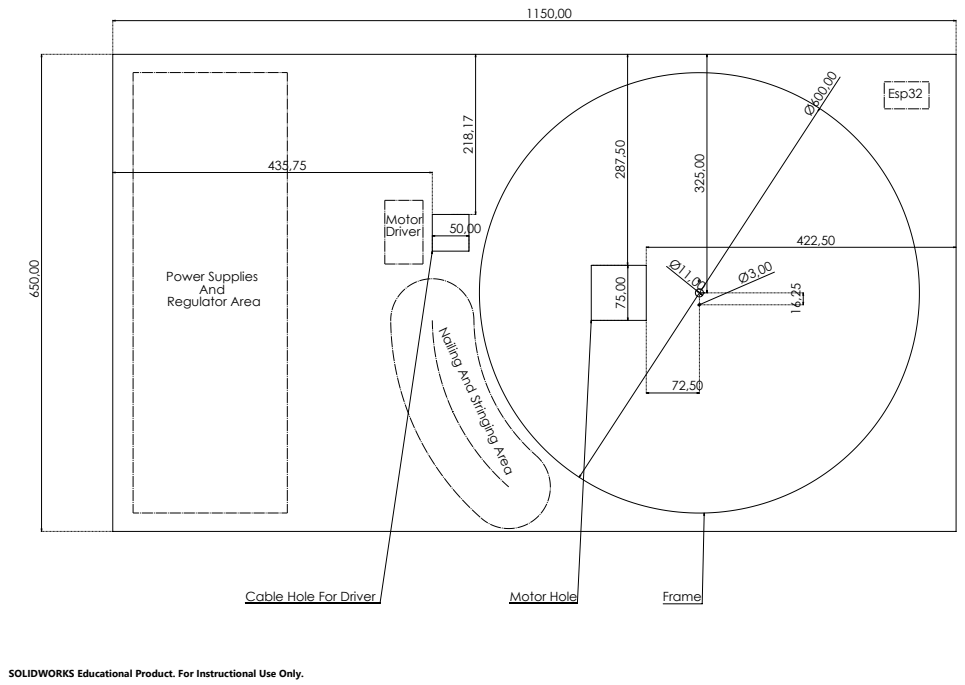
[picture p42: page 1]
Cable Hole For Driver; Motor Hole; Frame; Power Supplies Regulator Area

Nailing And Stringing Area

SOLIDWORKS Educational Product. For Instructional Use Only.

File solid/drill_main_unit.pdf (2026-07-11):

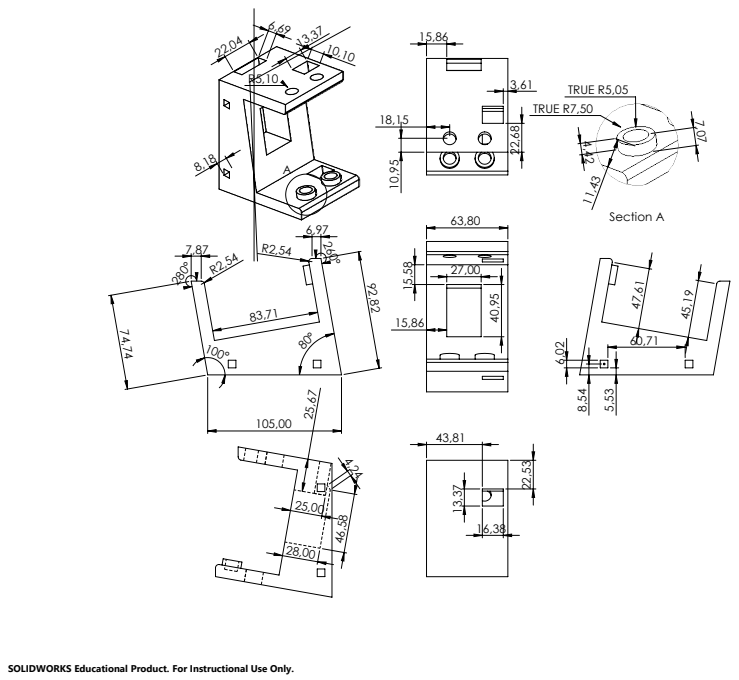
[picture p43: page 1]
TRUE R5,05 TRUE R7,50; Section A

SOLIDWORKS Educational Product. For Instructional Use Only.

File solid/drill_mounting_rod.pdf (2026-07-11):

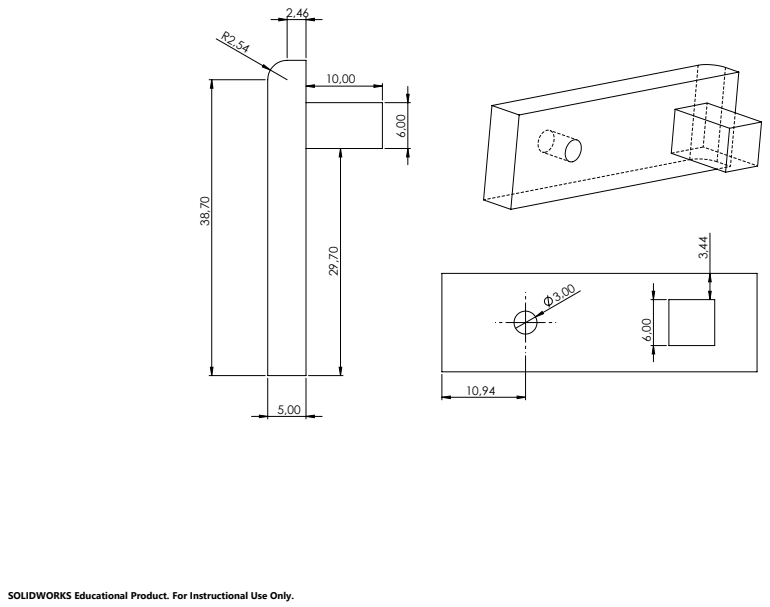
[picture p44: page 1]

SOLIDWORKS Educational Product. For Instructional Use Only.

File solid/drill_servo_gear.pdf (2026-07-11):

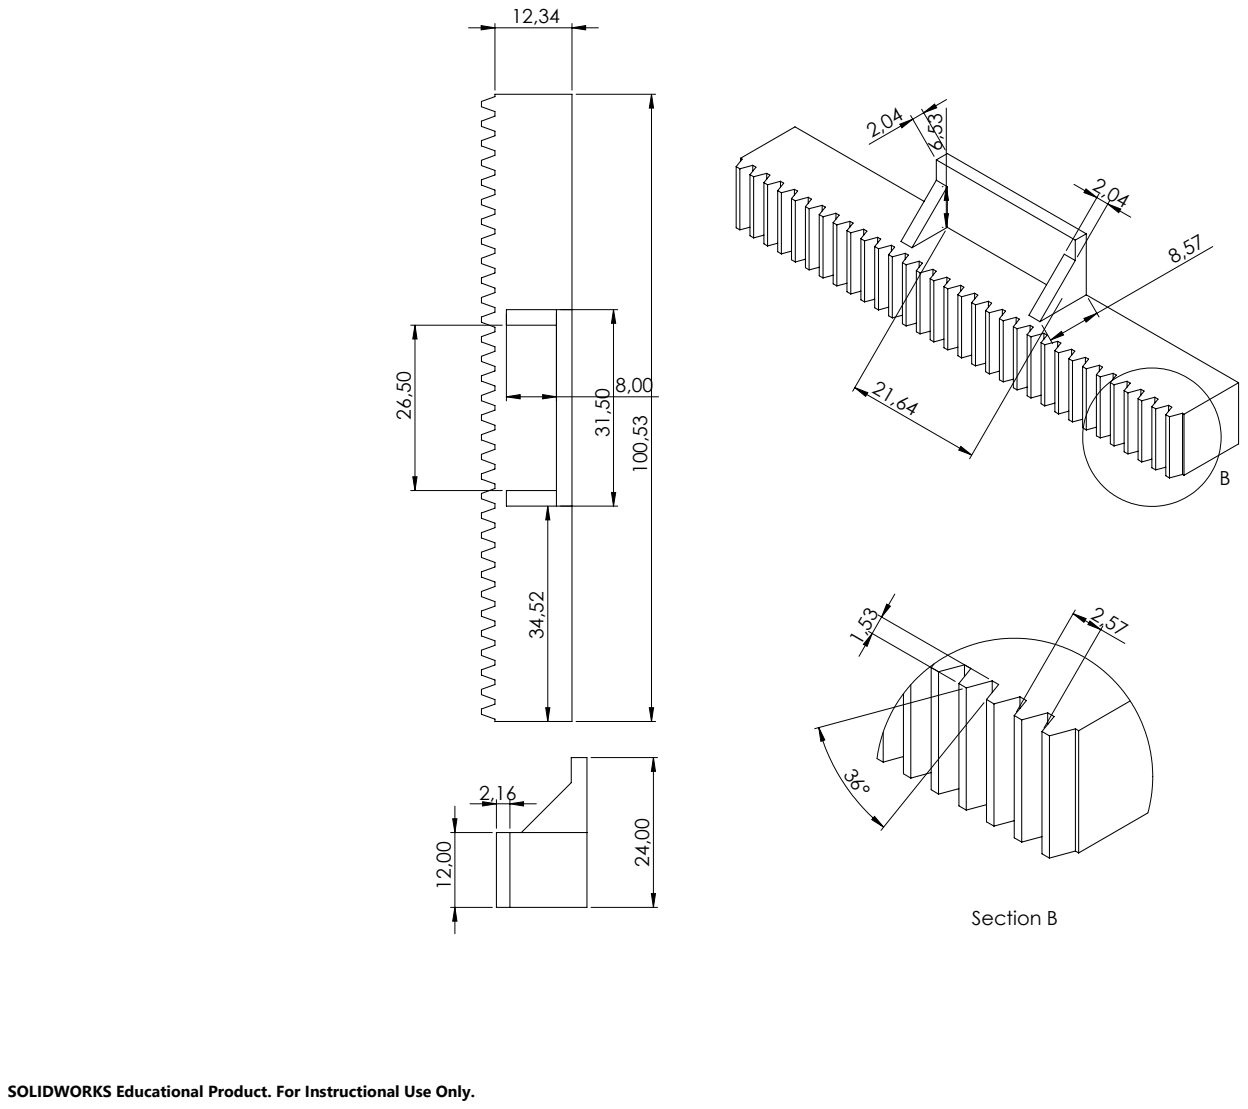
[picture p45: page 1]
Section B

SOLIDWORKS Educational Product. For Instructional Use Only.

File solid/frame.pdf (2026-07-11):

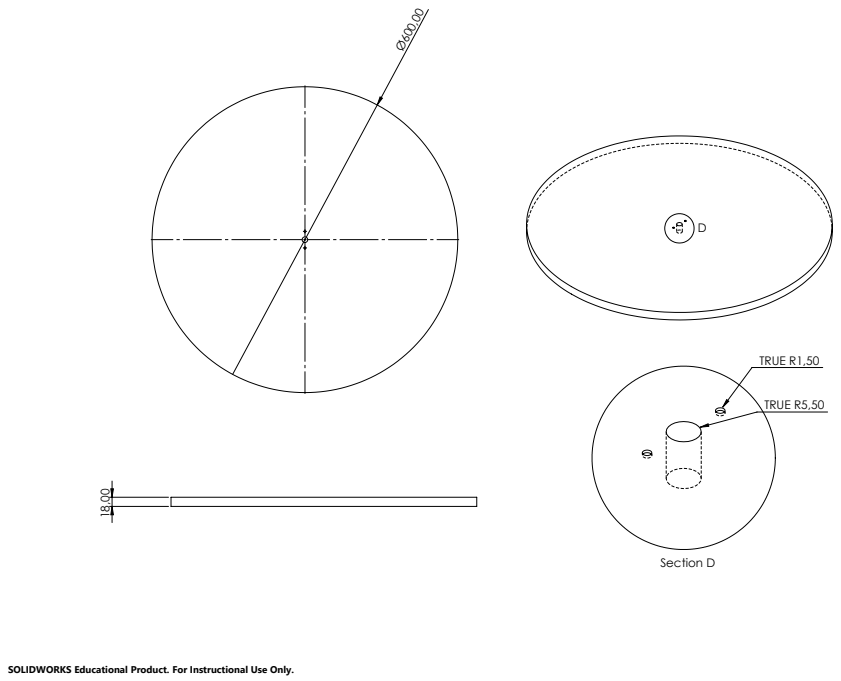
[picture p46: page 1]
TRUE R5,50; TRUE R1,50; Section D

SOLIDWORKS Educational Product. For Instructional Use Only.

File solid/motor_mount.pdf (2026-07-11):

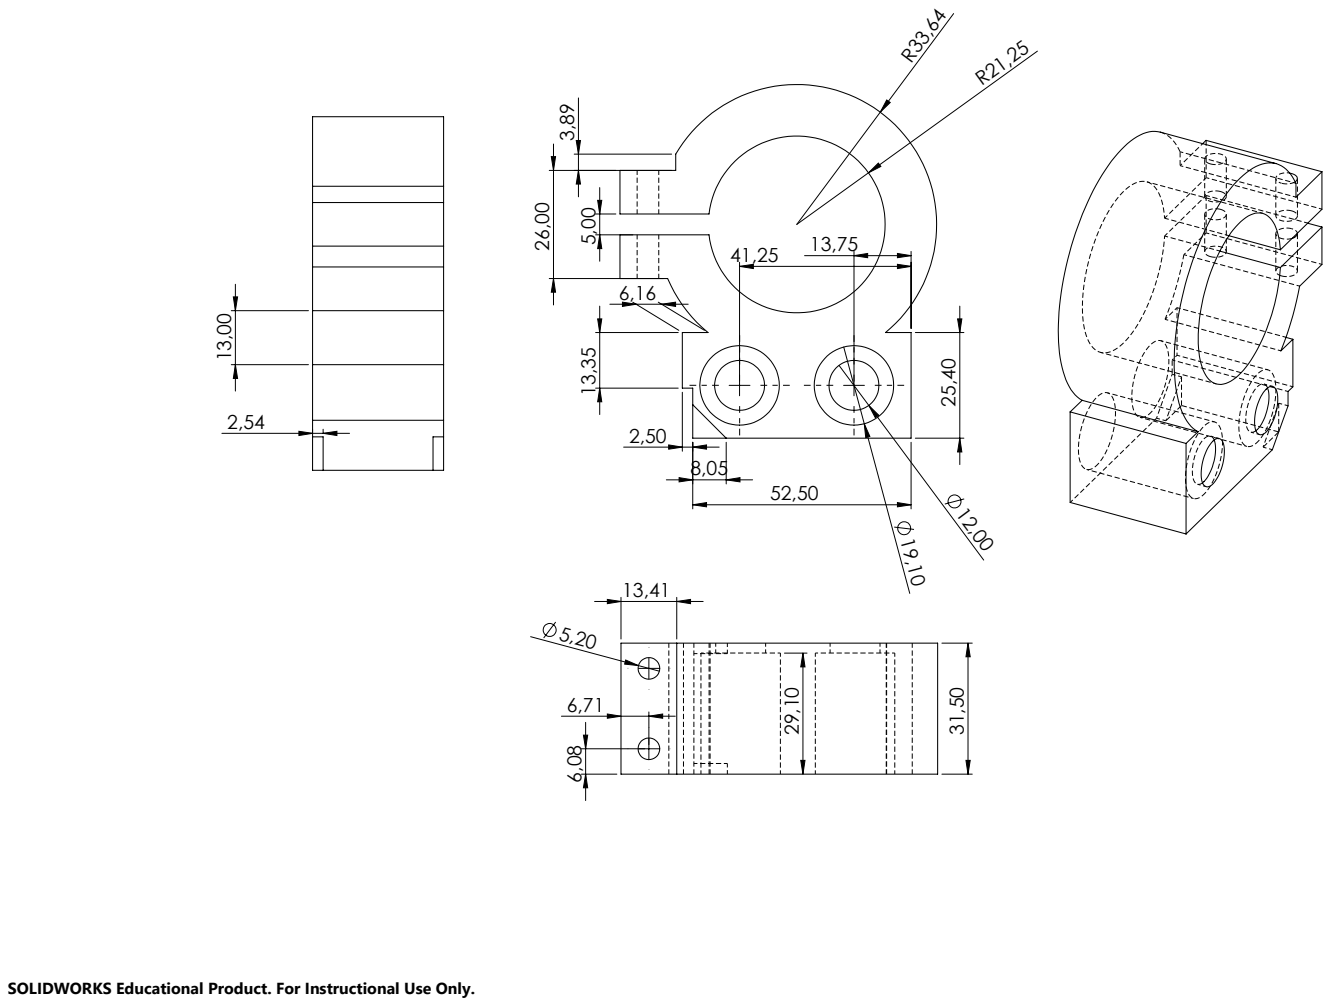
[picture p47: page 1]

SOLIDWORKS Educational Product. For Instructional Use Only.

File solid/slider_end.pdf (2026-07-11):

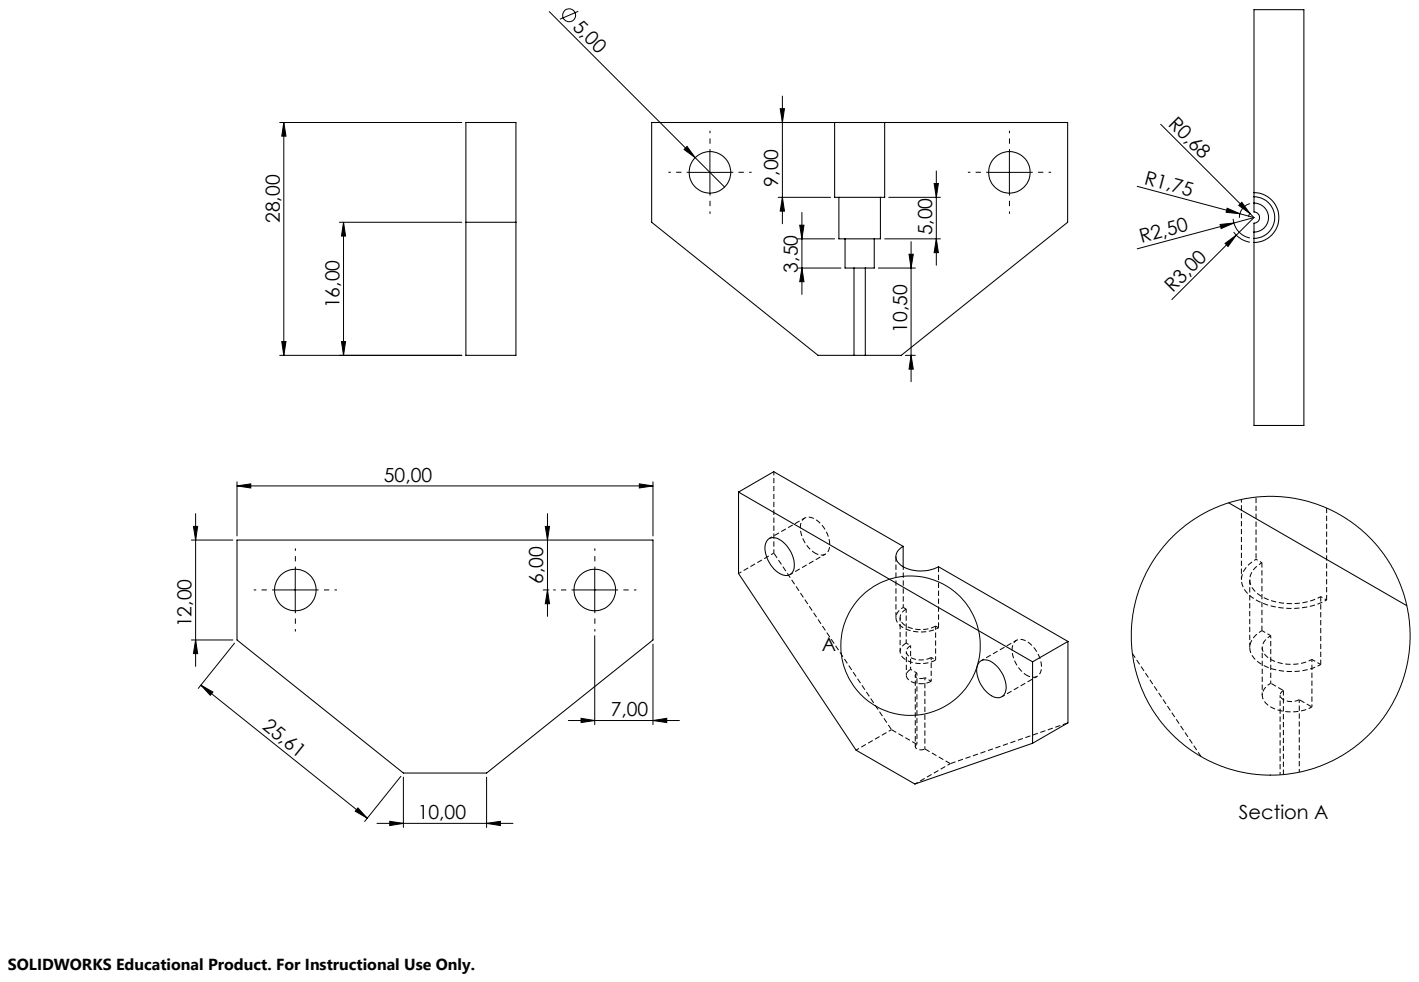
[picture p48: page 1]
Section A

SOLIDWORKS Educational Product. For Instructional Use Only.
